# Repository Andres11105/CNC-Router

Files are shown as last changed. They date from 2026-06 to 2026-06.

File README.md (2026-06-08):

# CNC Router

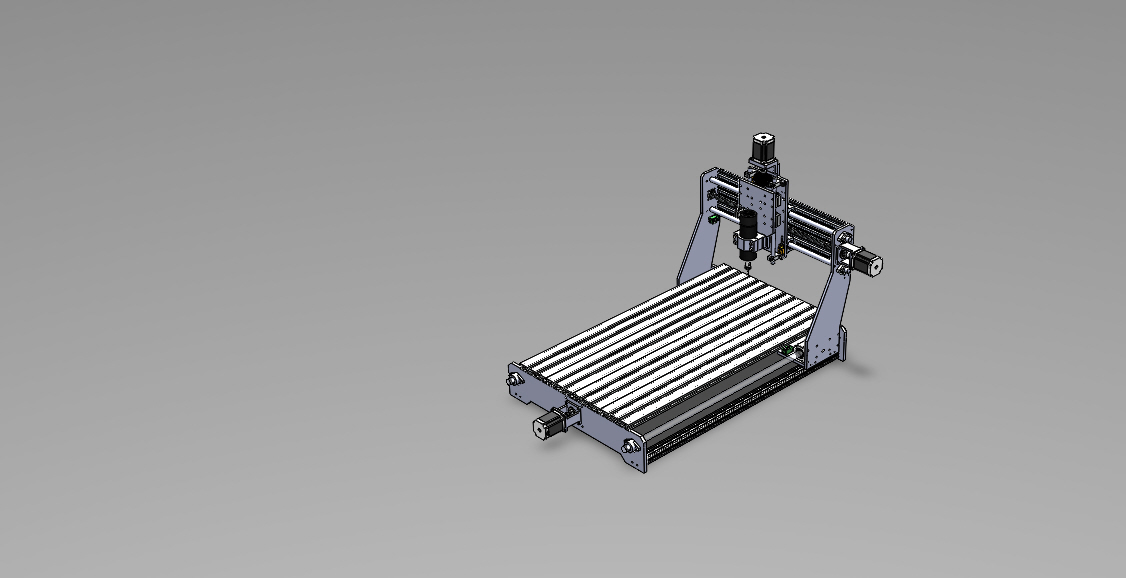
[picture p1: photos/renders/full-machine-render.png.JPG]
full-machine-render


CNC Router

Custom DIY CNC router based on ESP32 + FluidNC, designed for PCB prototyping, wood machining, acrylic fabrication and soft metal machining.

---

## Project Overview

This project documents the design and construction of a custom CNC router developed as an engineering and learning platform focused on:

- CNC machine development
- Embedded systems integration
- Mechanical design
- Electronics and motion control
- FluidNC firmware configuration
- CAD/CAM workflow
- Real-world troubleshooting and calibration

The machine is being developed with a strong focus on modularity, experimentation and practical engineering solutions.

---

## Project Goals

- Build a functional low-cost CNC platform
- Learn CNC machine engineering
- Experiment with ESP32 + FluidNC
- Prototype PCBs and small mechanical parts
- Improve electronics and firmware integration skills
- Document the complete development process

---

## Specifications

| Parameter | Value |
|---|---|
| Work Area | 220 x 430 x 120 mm |
| Controller | ESP32 6x_CNC_Controller + FluidNC + WebUI |
| Firmware | FluidNC |
| Motion System | Lead Screw |
| Machine Type | DIY CNC Router |
| Homing System | Enabled |
| Emergency Stop | Enabled |
| Probe Input | Enabled |

---

## Current Status

- [x] Mechanical structure
- [x] X/Y/Z movement
- [x] FluidNC configuration
- [x] Homing system
- [x] Emergency stop
- [x] Probe input
- [ ] Tool setter
- [x] Cable management
- [ ] Dust collection system
- [ ] Final enclosure

---

## Mechanical Design

The machine structure combines custom-designed components with commercially available mechanical parts.

Some reference CAD models such as motors, lead screws and standard mechanical components were obtained from public engineering libraries like GrabCAD to accelerate assembly and integration workflows.

---

## Electronics

Main electronics currently used in the project:

* ESP32-based "6x_CNC_Controller"
* FluidNC firmware
* Bart Dring WebUI interface
* Stepper motor drivers
* External power supply system
* Emergency stop (E-Stop) circuit
* Probe input system
* Homing/limit switches
* Motion control wiring
* Shielded signal and motor wiring
* Cooling system for drivers and electronics
* Spindle control interface
* USB and WiFi connectivity
* GPIO-based machine control inputs
* Custom machine wiring and cable routing

The electronics architecture focuses on modularity, reliability and ease of maintenance while keeping the system flexible for future upgrades and experimentation.

---

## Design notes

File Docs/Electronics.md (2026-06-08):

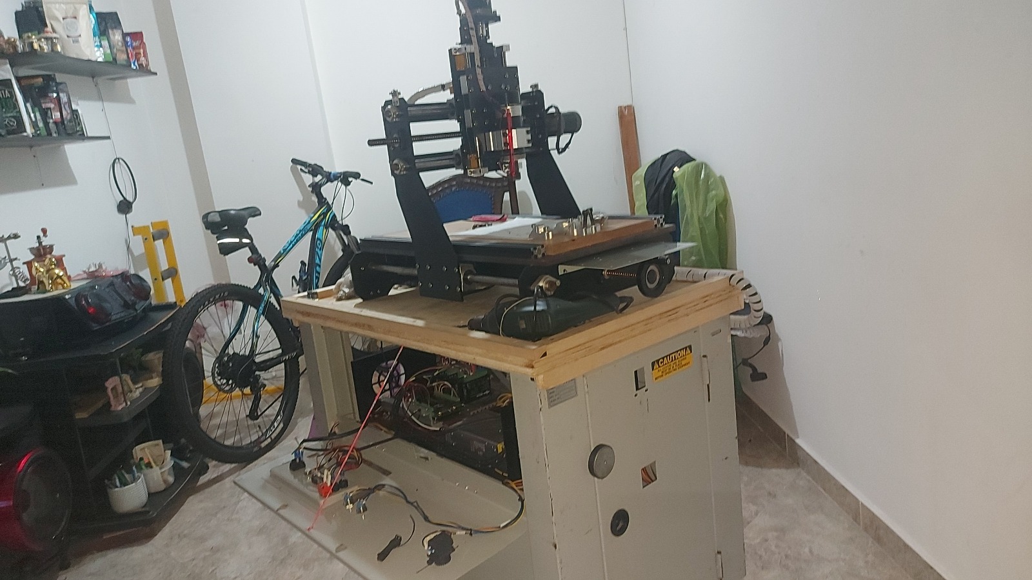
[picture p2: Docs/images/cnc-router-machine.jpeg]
CNC Router


# Electronics Overview

The CNC router uses an ESP32-based control system running FluidNC firmware combined with external motion control electronics and distributed power systems.

The electrical system was designed with a focus on:

* Modularity
* Accessibility
* Low-cost implementation
* Ease of maintenance
* Future scalability

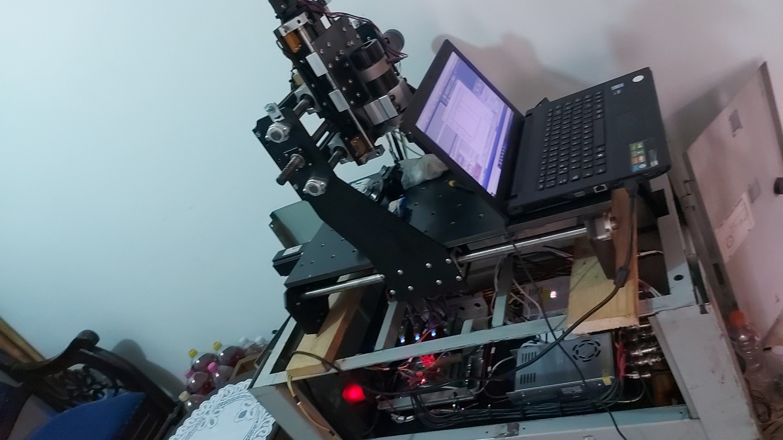
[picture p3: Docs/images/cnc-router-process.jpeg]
Router Assembly Process


---

## Main Electronics

Current electronics used in the machine:

| Component | Description |
| --- | --- |
| CNC Interface | ESP32 6x_CNC_Controller |
| Firmware | FluidNC |
| Motion Drivers | TB6600 stepper drivers |
| Stepper Motors | Nema23 stepper motors (~3Nm) |
| Spindle System | 500W 48V Brushless Spindle Kit |
| Spindle Driver | BLDC spindle driver |
| Main Motion Supply | 24V power supply |
| Spindle Supply | 48V power supply |
| Logic Supply | 12V power supply |
| Limit Switches | Inductive sensors |

The Y-axis motors are newer units while the X and Z axis motors were reused from previous CNC-related projects and experimentation platforms.

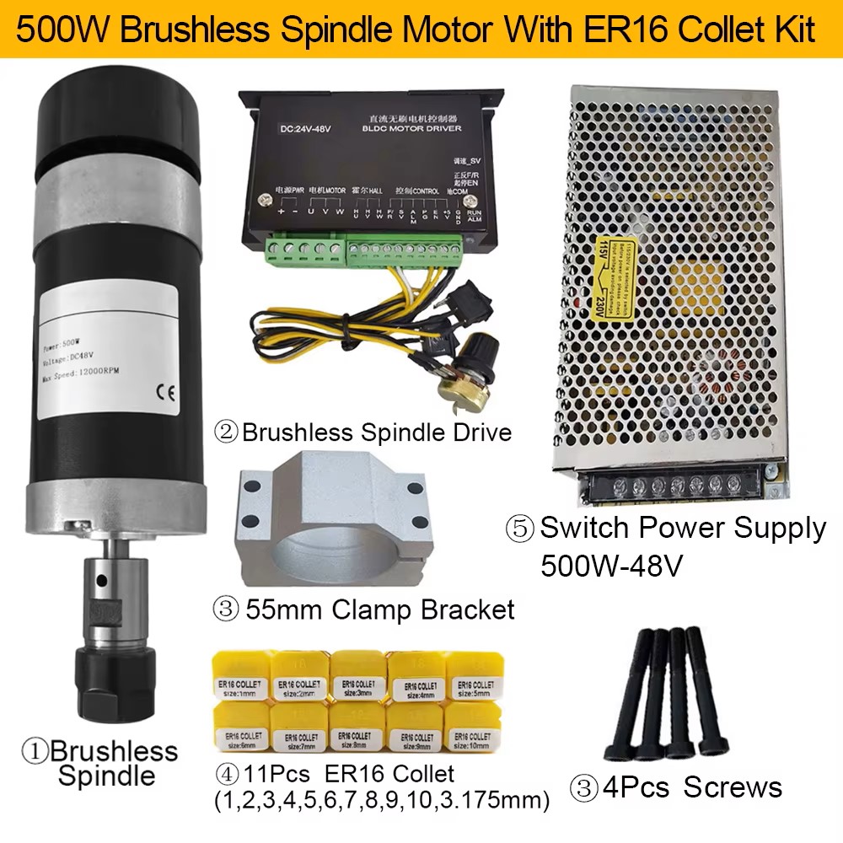
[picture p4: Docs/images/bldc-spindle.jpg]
BLDC Spindle

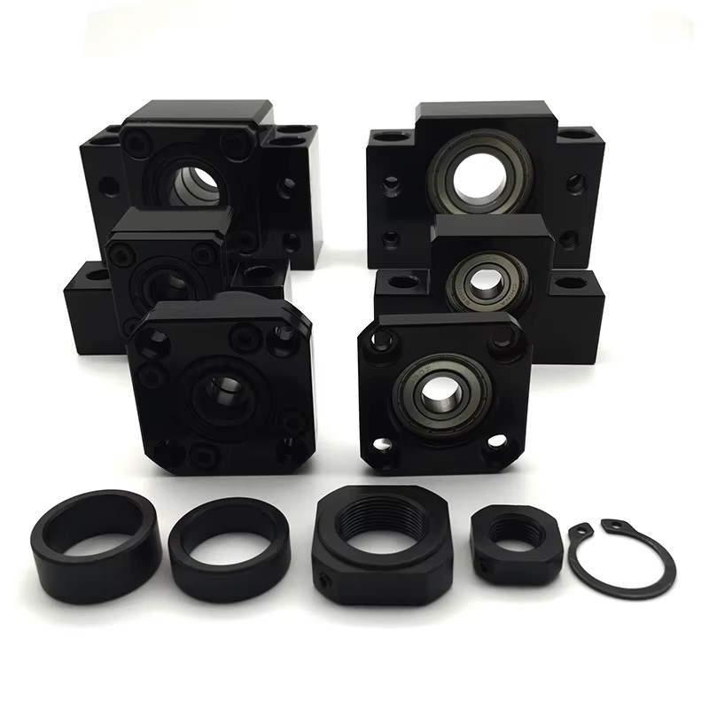
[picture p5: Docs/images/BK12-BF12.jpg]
BK12 and BF12 Supports

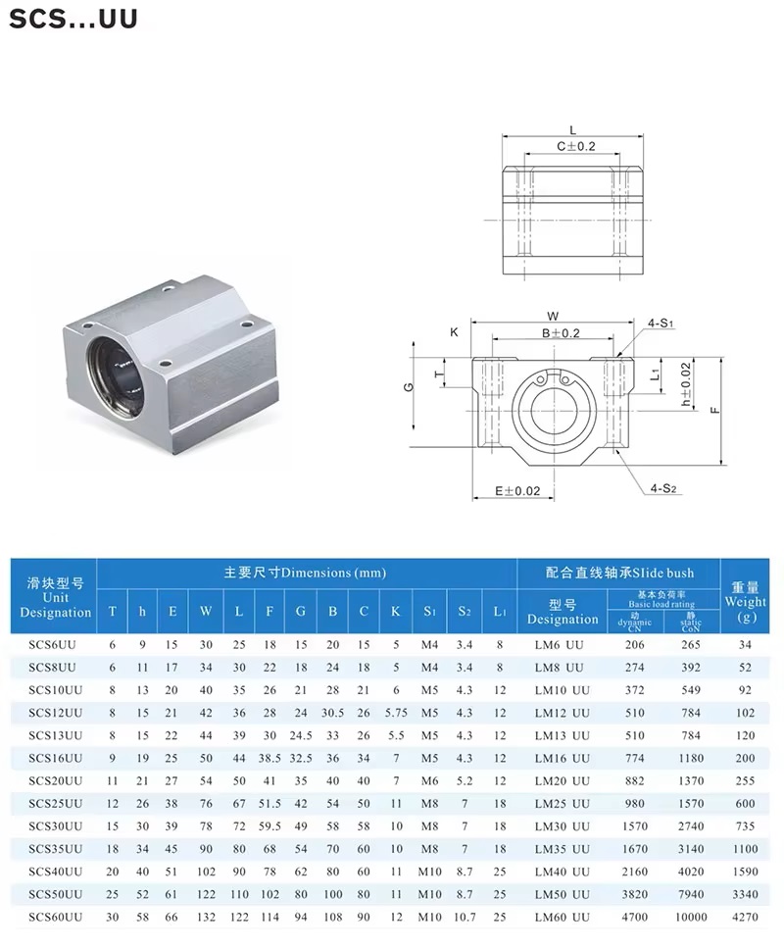
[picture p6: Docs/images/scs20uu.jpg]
SCS20UU Bearings

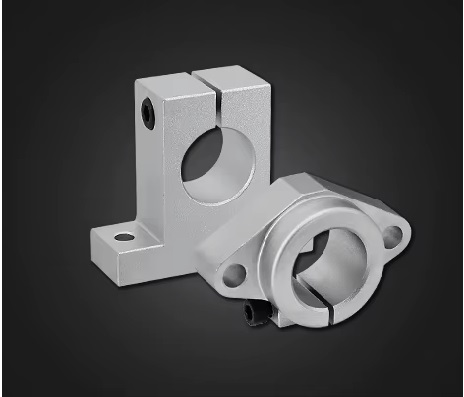
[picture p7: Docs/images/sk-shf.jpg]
SK and SHF Supports

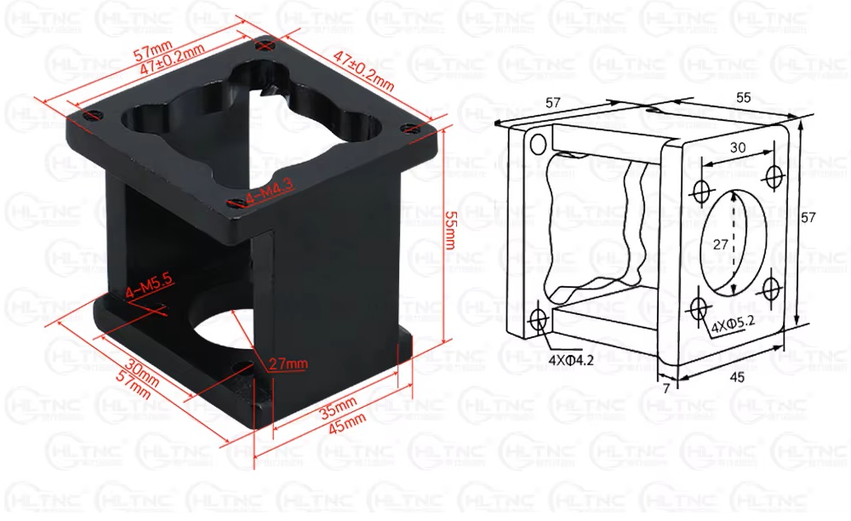
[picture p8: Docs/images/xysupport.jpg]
XY Axis Support
 
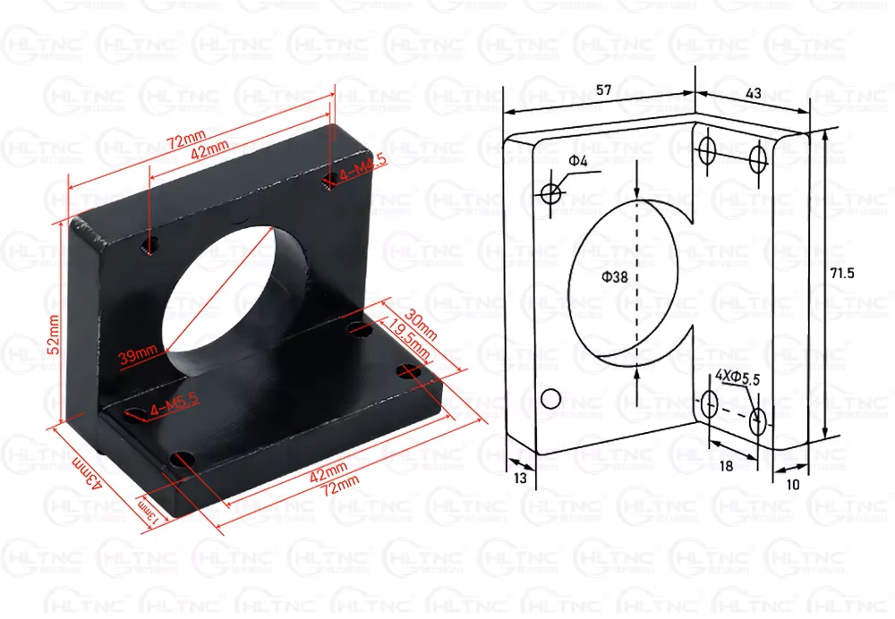
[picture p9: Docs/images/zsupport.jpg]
Z Axis Support


---

## CNC Interface

The machine currently uses an ESP32-based 6x_CNC_Controller running FluidNC firmware.

The controller ecosystem follows the hardware and firmware approach proposed by Bart Dring for FluidNC systems.

The interface includes:

* Start button
* Stop button
* Emergency stop input
* Probe input
* Homing system
* Manual controls
* External driver integration

A small cooling turbine is currently installed for airflow around the ESP32 interface and controller electronics.

---

## Spindle Configuration

The spindle system currently uses:

> DC Brushless Spindle Motor Kit 500W 48V Air Cooled

The spindle wiring was designed to support both:

* Manual spindle operation
* FluidNC-controlled operation

allowing flexible machine usage during testing, maintenance and firmware experimentation.

---

## Motion Control System

The motion system uses external TB6600 stepper drivers combined with Nema23 stepper motors.

Current machine motion architecture:

| Axis | Motor Type | Linear Shaft |
| --- | --- | --- |
| X Axis | Nema23 | 16 mm |
| Y Axis | Nema23 | 20 mm |
| Z Axis | Nema23 | 12 mm |

Inductive limit switches are currently used for homing and machine protection.

---

## Homing and Recovery System

During machine operation, certain failure conditions may leave the limit switches continuously activated, preventing normal machine movement.

To simplify machine recovery during these situations, an additional manual override push-button was implemented.

This button temporarily interrupts the limit switch signal, allowing the machine to be manually moved back into a safe position before executing the homing process again.

This solution was implemented as a practical recovery mechanism during testing and troubleshooting procedures common in DIY CNC developments.

---

## Wiring Philosophy

The electrical system was wired with a modular and serviceable approach in mind.

Special attention was given to separating:

* Power distribution
* Signal wiring
* Motion control wiring
* Safety systems

The electronics enclosure remains easily accessible for:

* Maintenance
* Troubleshooting
* Firmware updates
* Driver replacement
* Future upgrades

Further improvements such as advanced cable management, EMI reduction and enclosure refinements may be implemented in future revisions of the project.

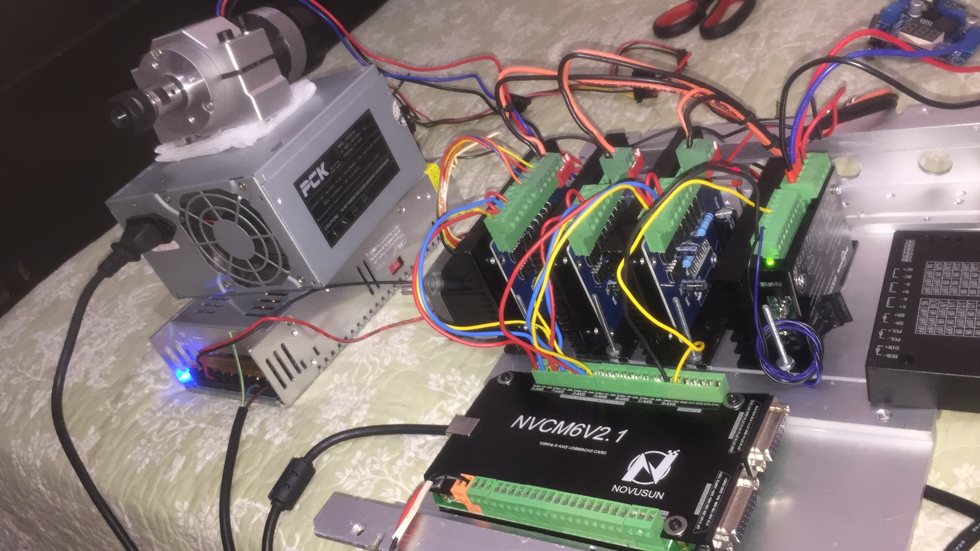
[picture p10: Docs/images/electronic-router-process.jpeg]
Electronics Assembly Process

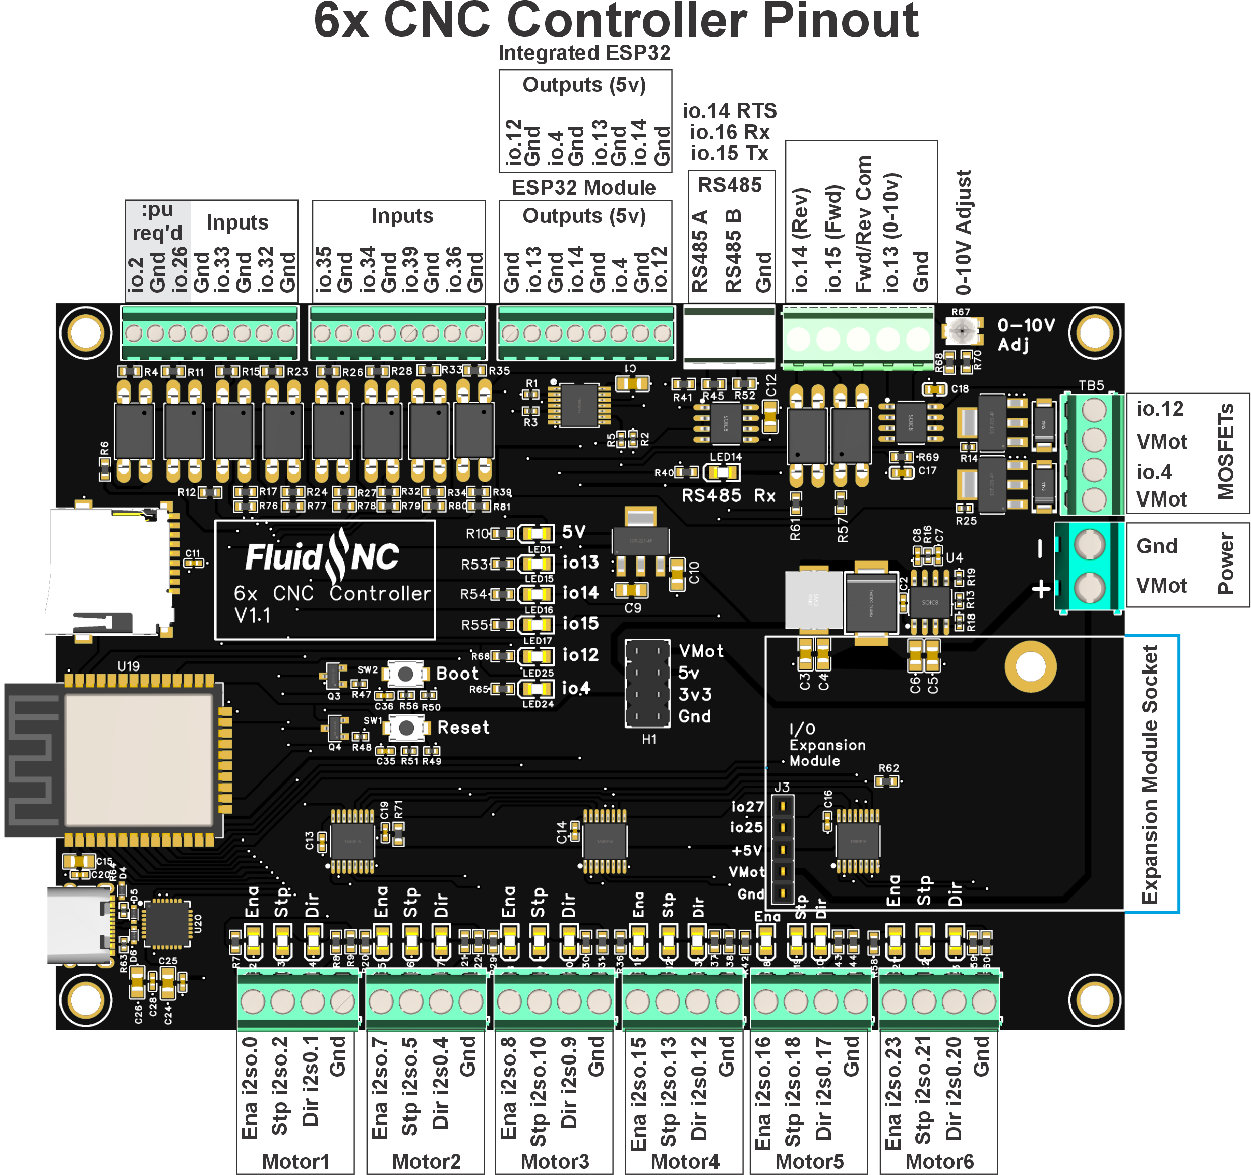
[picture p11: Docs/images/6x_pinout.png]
6x CNC Controller Pinout

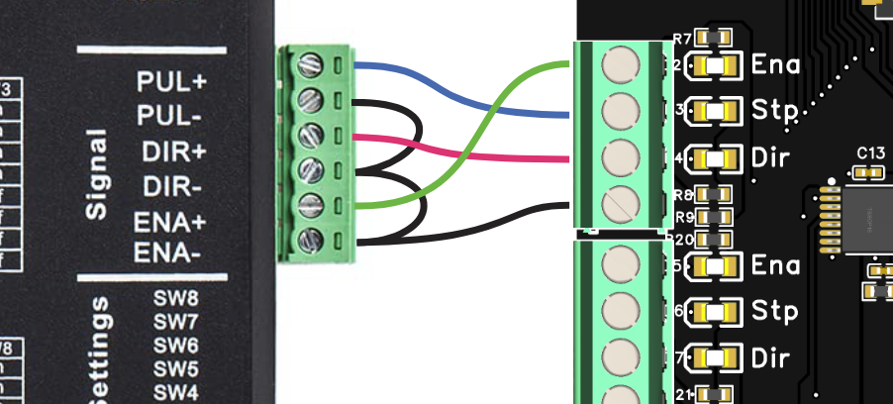
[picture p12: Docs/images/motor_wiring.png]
Motor Wiring

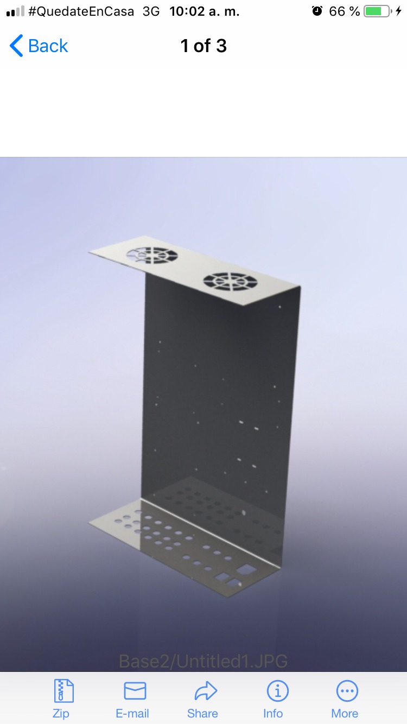
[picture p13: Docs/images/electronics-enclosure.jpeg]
Electronics Enclosure


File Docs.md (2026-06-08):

# Mechanical Design Philosophy

Mechanical Design

This section documents the engineering decisions, manufacturing processes, mechanical challenges and design philosophy behind the CNC router development.

The machine was developed as a long-term DIY engineering and learning project focused on CNC systems, electronics integration, firmware configuration and mechanical design.

---

## Industrial Inspiration

During an internship process at EAFIT University in Medellín, Colombia, conversations with the CNC laboratory machine operator provided valuable practical insight into industrial CNC machine design principles.

Special emphasis was placed on the importance of:

* Recirculating ball screws
* Mechanical tolerances
* Structural rigidity
* Backlash reduction

After researching the topic further, the importance of motion precision and tolerance management became evident, especially within the limitations commonly present in DIY CNC developments.

For this reason, 1605 recirculating ball screws were implemented on all machine axes to reduce backlash and improve positional accuracy.

---

## Project Philosophy

This CNC router was developed primarily as:

* A learning platform
* A long-term hobby project
* An engineering experimentation platform
* A low-cost CNC development environment

Because the project was built using limited personal resources, considerable effort was dedicated to optimizing:

* Material selection
* Manufacturing methods
* Component acquisition
* Mechanical design
* Scalability possibilities

---

## Prototyping Strategy

Multiple laser-cut MDF prototypes were manufactured during early development stages due to their:

* Low manufacturing cost
* Fast fabrication time
* Easy modification process
* Material accessibility

This prototyping stage allowed validation of:

* Structural dimensions
* Axis positioning
* Mechanical clearances
* Motion integration
* Assembly procedures

before proceeding to the fabrication of the final RH steel structural components.

The MDF prototyping stage proved extremely valuable for identifying mechanical issues early while reducing material waste and manufacturing costs.

---

## Structural Material Selection

RH steel was selected as the primary structural material mainly due to:

* Budget limitations
* Local material availability
* Manufacturing accessibility

Although RH steel adds considerable weight compared to aluminum CNC structures, the additional mass contributes positively to:

* Vibration damping
* Structural rigidity
* Machine stability

However, the increased structural weight also introduces:

* Higher moving mass
* Increased mechanical stress
* Greater flexion forces
* More demanding alignment procedures

For this project, the added rigidity and lower manufacturing cost were considered acceptable trade-offs.

---

## Workspace Optimization

The machine dimensions were intentionally designed to fit within the footprint of a standard desk workspace.

This decision provided several advantages:

| Advantage | Benefit |
| --- | --- |
| Compact Size | Easier workspace integration |
| Reduced Material Usage | Lower manufacturing costs |
| Improved Accessibility | Easier assembly and maintenance |
| Desktop Footprint | Better adaptation for hobby/lab environments |

while still maintaining enough working area for:

* PCB prototyping
* Wood machining
* Acrylic machining
* Soft metal experimentation

---

## Modular Design

The machine was designed using independent mechanical modules to simplify:

* Manufacturing
* Assembly
* Maintenance
* Future upgrades

### Current Machine Architecture

| Module | Description |
| --- | --- |
| Bed Module | Base structure and transmission |
| Gantry Module | Main bridge structure |
| X-Axis Module | Horizontal displacement system  |
| Z-Axis Module | Vertical motion system |

This modular approach allows individual sections of the machine to be modified or redesigned without rebuilding the complete structure.

---

## Manufacturing Process

Laser cutting was used extensively during both:

* MDF prototyping
* RH steel fabrication

The structural steel plates were laser-cut according to CAD designs; however, some hole tolerances were affected because laser cutting clearances were not fully considered during the design phase.

### Manufacturing Corrections

* Some holes became oversized
* Larger fasteners became necessary
* Additional alignment corrections were required
* Some assemblies required manual adjustment during installation

Several structural alignment corrections also became necessary during assembly due to distortions introduced by welding processes.

> Machine squaring and alignment remain one of the primary areas for future improvement.

---

## Mechanical Challenges

Like many DIY CNC developments, the project presents several common engineering challenges, including:

* Structural flexion caused by machine weight and machining forces
* Mechanical alignment complexity
* Welding-induced dimensional deviations
* Motion system tolerances
* Gantry squaring adjustments

### Current Mechanical Behavior

| Characteristic | Current Result |
| --- | --- |
| Structural Rigidity | Acceptable |
| Vibration Levels | Relatively controlled |
| Backlash Reduction  | Significantly improved |
| Alignment Accuracy  | Requires future improvements |

Despite the machine weight, vibration levels have remained relatively controlled due to the rigidity and damping effect provided by the steel structure.

Backlash reduction has been significantly improved through the use of recirculating ball screws compared to lower-cost transmission alternatives.

---

## Components and Motion System

Several critical mechanical components were acquired through commercial suppliers such as AliExpress to reduce manufacturing complexity and improve reliability.

### Main Purchased Components

* Stepper motor mounts
* Linear shaft supports
* Linear shafts
* BK/BF supports
* Sensors
* Stepper motors
* Spindle system
* Motion accessories

---

## Linear Shaft Configuration

| Axis | Diameter |
| --- | --- |
| Z Axis | 12 mm |
| X Axis | 16 mm |
| Y Axis | 20 mm |

The larger Y-axis shafts were selected due to the higher structural load requirements of the machine.

---

## Motion System

| Component | Specification |
| --- | --- |
| Ball Screws | 1605 Recirculating Ball Screws |
| Support System | BK/BF Supports |
| Linear System | Hardened Steel Shafts |
| Controller Platform | ESP32 + FluidNC |

The CNC controller interface was acquired through ELECROW following the recommendations and hardware ecosystem proposed by Bart Dring for FluidNC systems.

---

## Maintenance and Accessibility

The motion system and linear components remain externally accessible, simplifying:

* Inspection
* Cleaning
* Lubrication
* Preventive maintenance

Although this exposes the system to dust and debris contamination, it considerably improves:

* Maintenance accessibility
* Serviceability
* Mechanical inspection
* Upgrade possibilities

---

## Scalability and Future Upgrades

One of the primary advantages of DIY CNC platforms is their scalability and adaptability.

Virtually any subsystem may be upgraded or redesigned, including:

* Spindle systems
* Motor configurations
* Drivers
* Bearings
* Linear systems
* Controllers
* Firmware interfaces

### Potential Upgrade Consequences

| Upgrade | Possible Required Changes |
| --- | --- |
| Larger Spindle | Stronger Z-axis support |
| Bigger Motors | Driver replacement |
| Higher Speed Motion | Structural reinforcement  |
| Heavier Components  | Motion recalibration |

These modifications typically introduce secondary engineering consequences requiring:

* Additional redesign
* Structural reinforcement
* Motion recalibration
* Firmware adjustments

---

## Development Philosophy

The objective of this project is not only to build a functional CNC machine, but also to document the complete engineering process behind a real-world DIY CNC development platform.

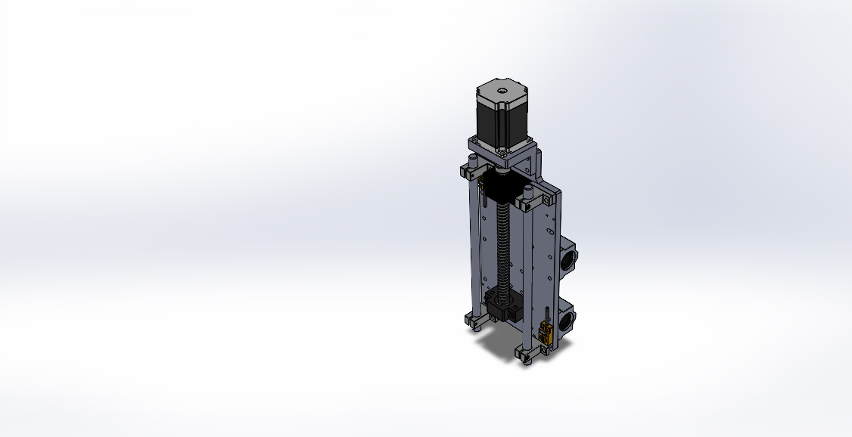
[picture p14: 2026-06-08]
photos/renders/DeslizableEjeX-render.JPG

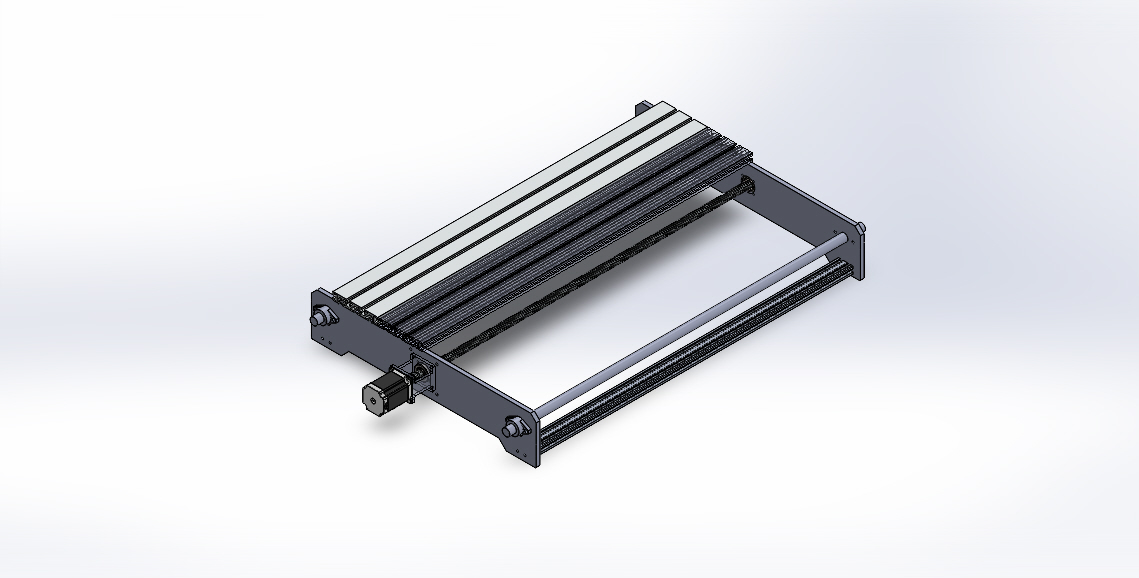
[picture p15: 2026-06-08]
photos/renders/Axis-Y-render.JPG

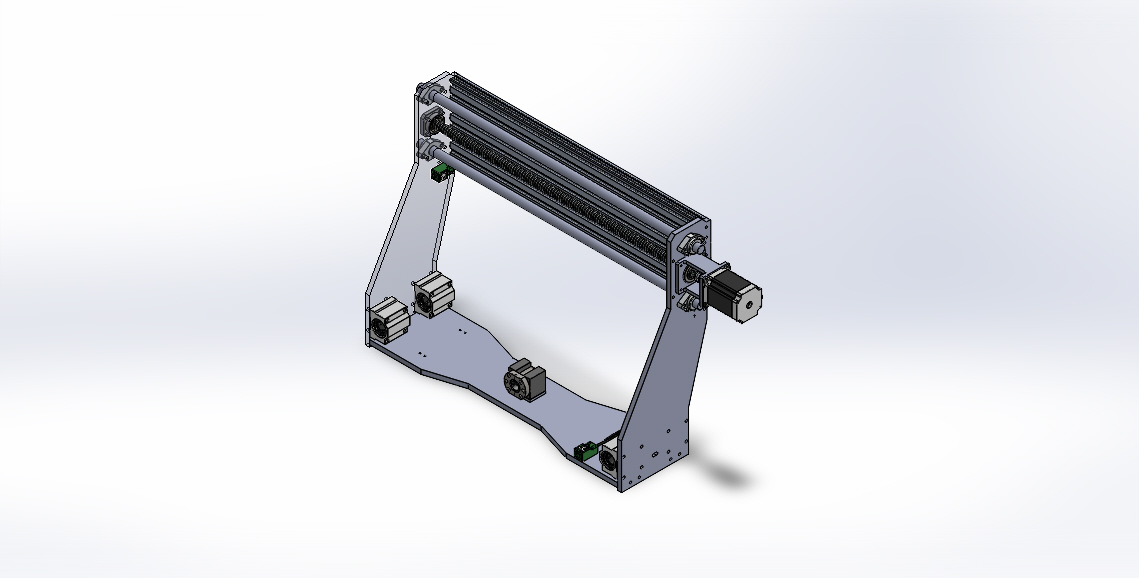
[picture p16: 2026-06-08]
photos/renders/Axis-X-render.JPG

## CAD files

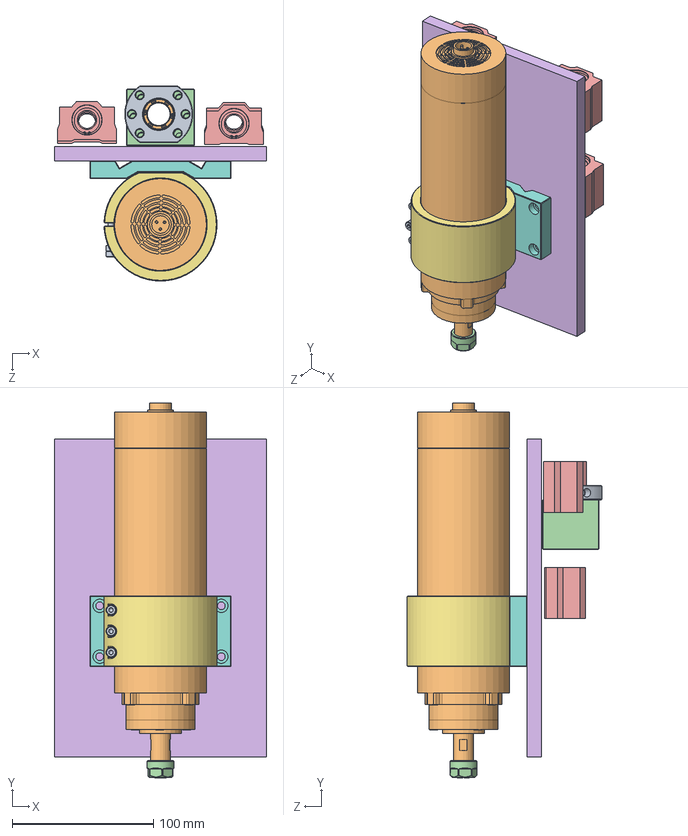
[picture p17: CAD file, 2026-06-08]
Cad/EnsamblajeZ.SLDASM
150.0 x 265.2 x 138.0 mm
SFU1605-1610-1
SFU1605-1610-3
SFU1605-1610-2
HD16
SC12UU x 4
Pieza3
CNCM.01.06.201
CNCM.01.06.202
socket head cap screw_am x 7
Шпиндель 1,5 кВт
ER11
ER11-T1

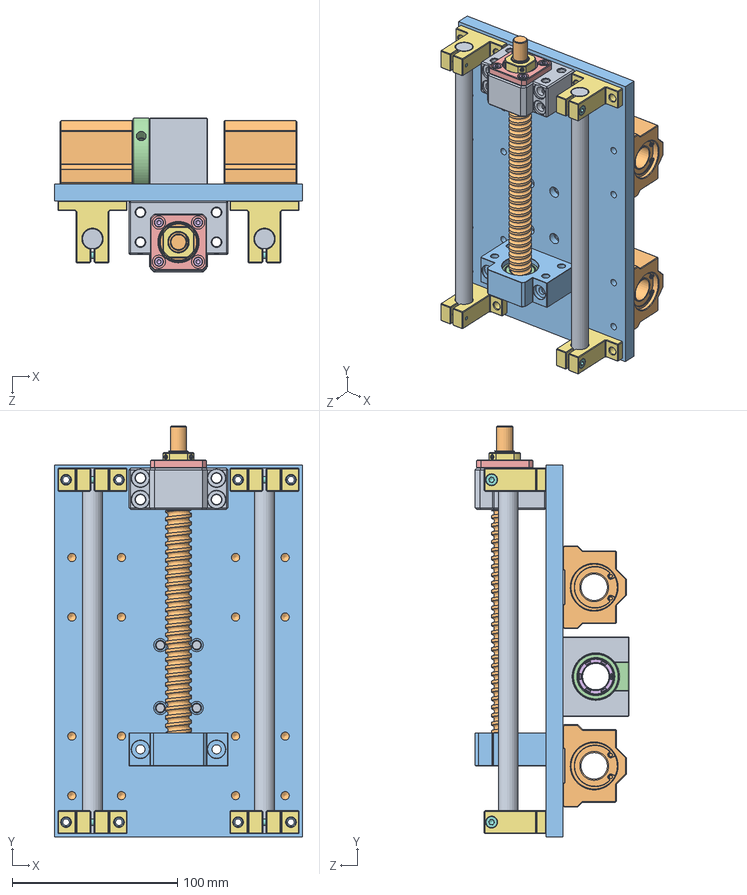
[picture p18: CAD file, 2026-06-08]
Cad/DeslizableEjeX.SLDASM
150.0 x 248.5 x 93.0 mm
HD16
sc16uu_bearing x 4
Pieza1
SFU1605-1610-1
SFU1605-1610-3
SFU1605-1610-2
Shaft support SK12 x 4
m4x16 x 4
BK12-1
BK12-2 x 2
BK12-3 x 2
6001-Bearing x 2
BK12-4
socket head cap screw_din x 4
BK12-5
socket set screw cup point_din x 2
Shaft200mm x 2
RM1605-C7 L200
BF12
6000Z

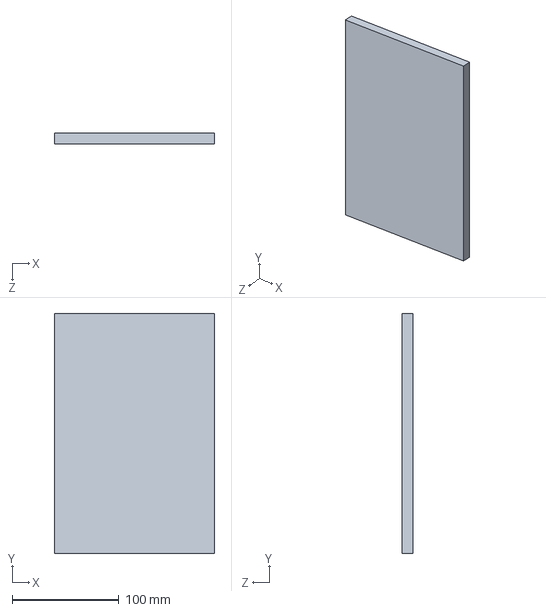
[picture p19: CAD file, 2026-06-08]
Cad/Pieza3.SLDPRT
150.0 x 225.0 x 10.0 mm

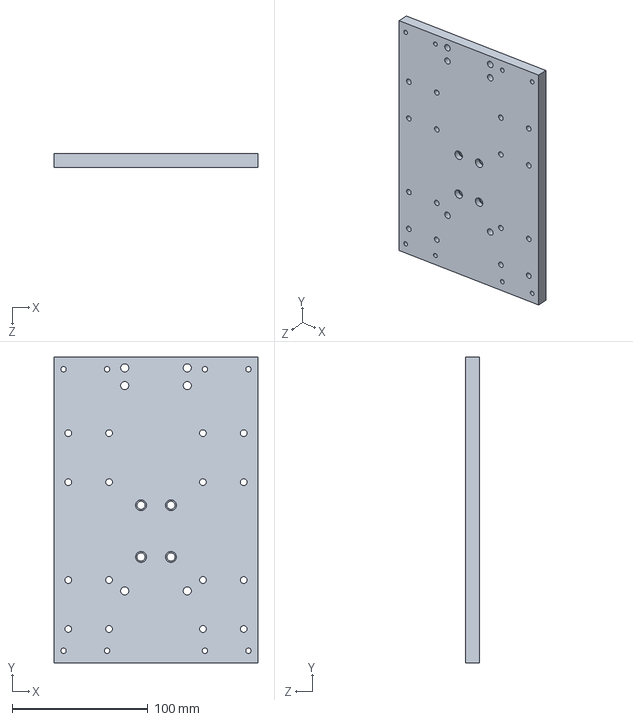
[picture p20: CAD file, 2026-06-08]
Cad/Pieza1.SLDPRT
150.0 x 225.0 x 10.0 mm

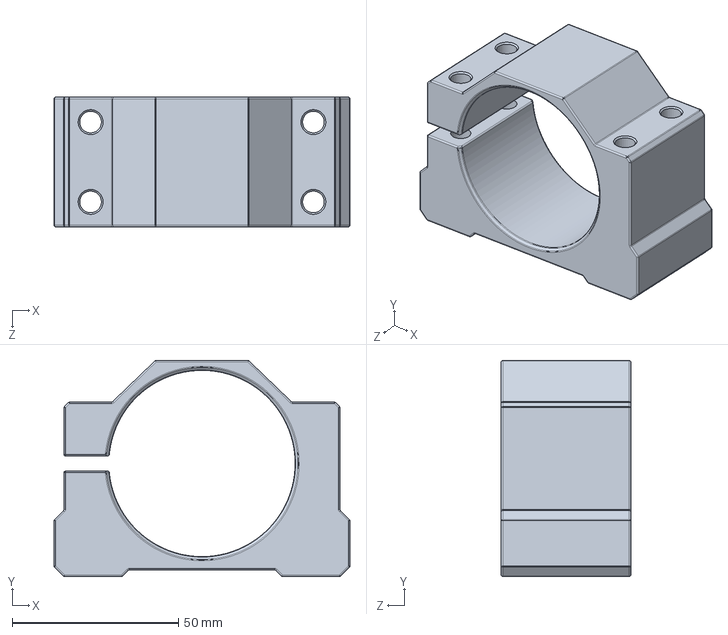
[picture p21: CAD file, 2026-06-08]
Cad/56.SLDPRT
89.0 x 65.0 x 39.0 mm

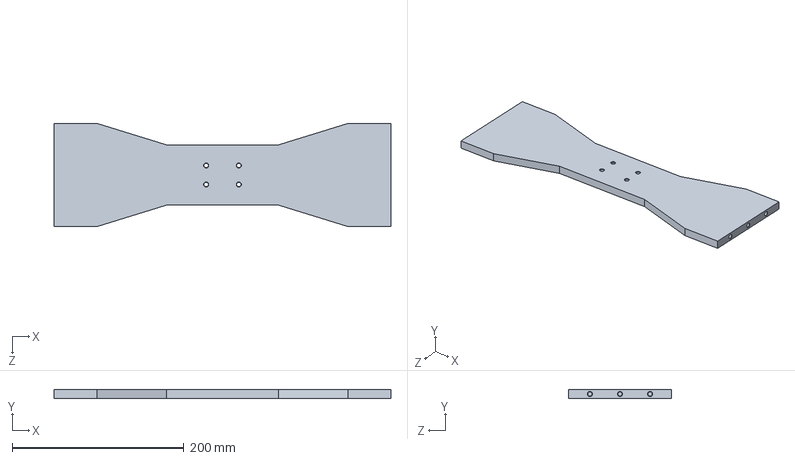
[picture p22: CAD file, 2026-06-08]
Cad/Pieza2.SLDPRT
392.0 x 10.0 x 120.0 mm

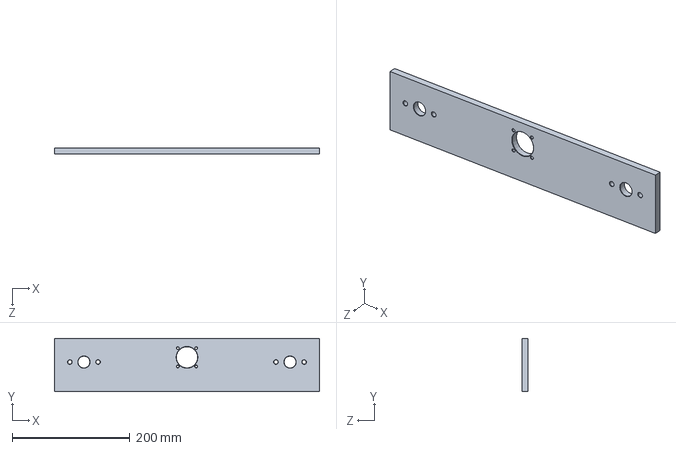
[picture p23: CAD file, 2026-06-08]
Cad/PiezaFrontalBaseY.SLDPRT
450.0 x 90.0 x 10.0 mm

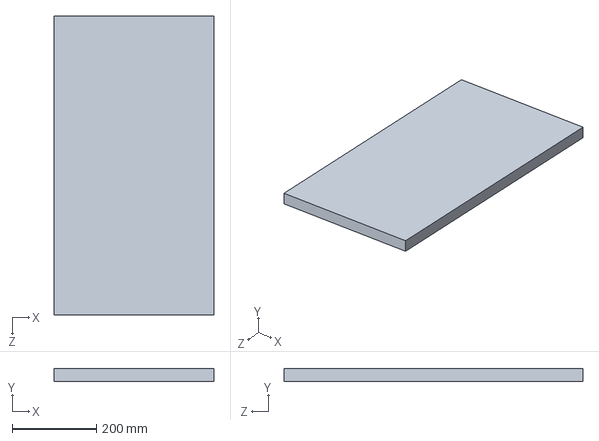
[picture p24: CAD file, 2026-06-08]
Cad/Pieza4.SLDPRT
380.0 x 30.0 x 710.0 mm

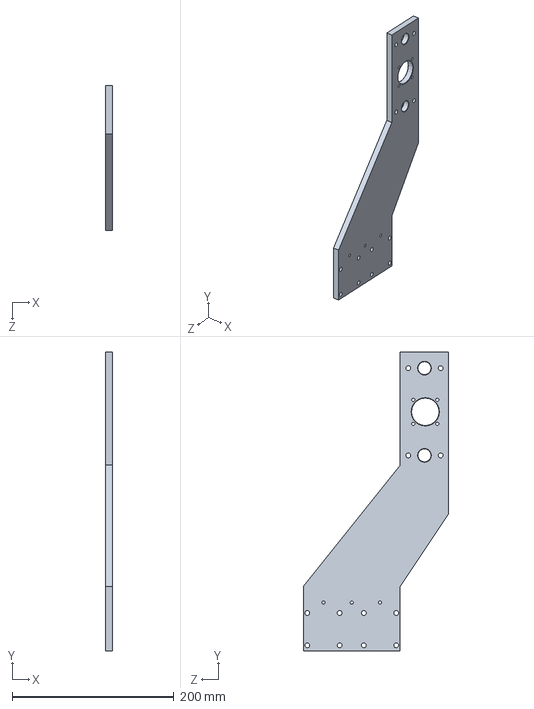
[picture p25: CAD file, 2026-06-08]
Cad/verticalYizqq.SLDPRT
9.00 x 370.0 x 180.0 mm

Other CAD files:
Cad/PiezaTraseraBaseY.SLDPRT
Cad/verticalYder.SLDPRT

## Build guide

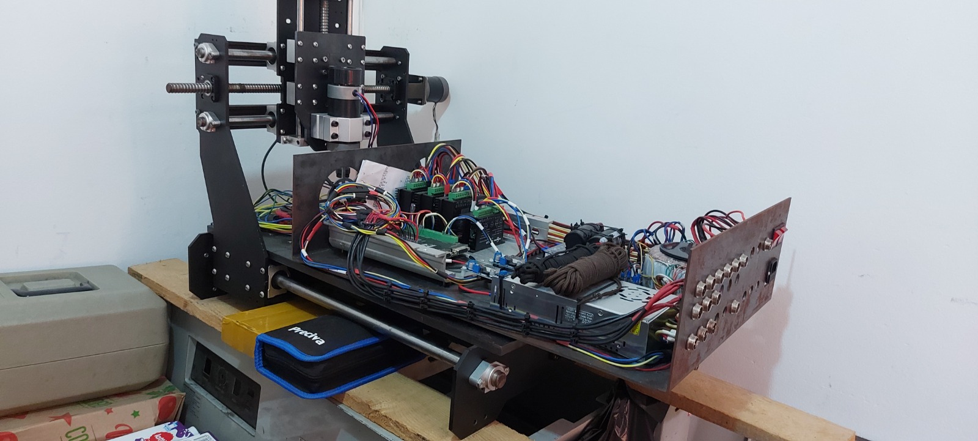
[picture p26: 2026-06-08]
Docs/images/wiring-process.jpeg

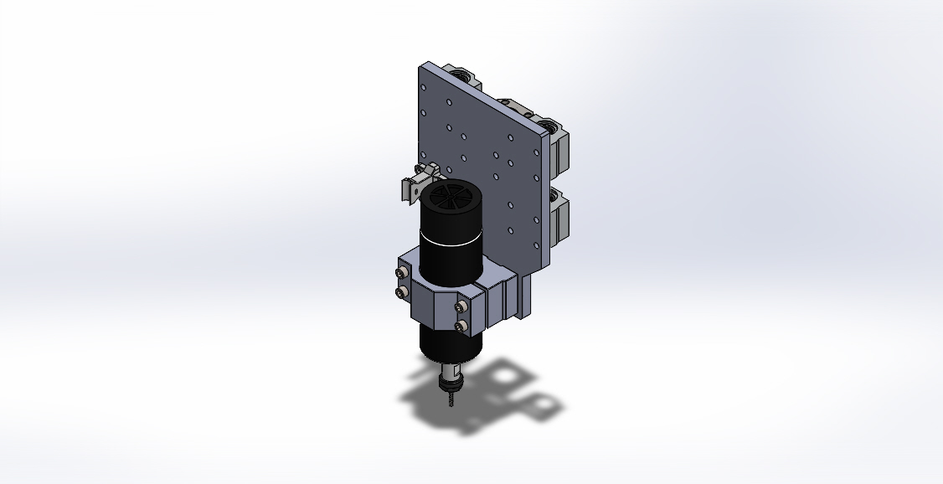
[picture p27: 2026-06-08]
photos/renders/EnsamblajeZ-render.JPG

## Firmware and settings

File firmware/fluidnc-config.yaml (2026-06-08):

board: 6x CNC Controller
name: xyz 10v Pendant
meta: (13-03-2025) by Andres11105

stepping:
  engine: I2S_STREAM
  idle_ms: 60000
  pulse_us: 4
  dir_delay_us: 1
  disable_delay_us: 0

axes:
  shared_stepper_disable_pin: NO_PIN
  x:
    steps_per_mm: 320.000
    max_rate_mm_per_min: 1500.000
    acceleration_mm_per_sec2: 100.000
    max_travel_mm: 220.000
    soft_limits: true
    homing:
      cycle: 2
      positive_direction: false
      mpos_mm: 4.000
      feed_mm_per_min: 500.000
      seek_mm_per_min: 800.000
      settle_ms: 500
      seek_scaler: 1.100
      feed_scaler: 1.100

    motor0:
      limit_neg_pin: NO_PIN
      limit_pos_pin: NO_PIN
      limit_all_pin: gpio.2:low:pu
      hard_limits: true
      pulloff_mm: 5.000
      standard_stepper:
        step_pin: I2SO.2
        direction_pin: I2SO.1:low
        disable_pin: I2SO.0

  y:
    steps_per_mm: 320.000
    max_rate_mm_per_min: 1500.000
    acceleration_mm_per_sec2: 100.000
    max_travel_mm: 420.000
    soft_limits: true
    homing:
      cycle: 2
      positive_direction: false
      mpos_mm: 4.000
      feed_mm_per_min: 500.000
      seek_mm_per_min: 800.000
      settle_ms: 500
      seek_scaler: 1.100
      feed_scaler: 1.100

    motor0:
      limit_neg_pin: NO_PIN
      limit_pos_pin: NO_PIN
      limit_all_pin: gpio.26:low:pu
      hard_limits: true
      pulloff_mm: 5.000
      standard_stepper:
        step_pin: I2SO.5
        direction_pin: I2SO.4:high
        disable_pin: I2SO.7

  z:
    steps_per_mm: 320.000
    max_rate_mm_per_min: 1000.000
    acceleration_mm_per_sec2: 100.000
    max_travel_mm: 120.000
    soft_limits: false
    homing:
      cycle: 1
      positive_direction: true
      mpos_mm: 100.000
      feed_mm_per_min: 500.000
      seek_mm_per_min: 800.000
      settle_ms: 500
      seek_scaler: 1.100
      feed_scaler: 1.100

    motor0:
      limit_neg_pin: NO_PIN    
      limit_pos_pin: NO_PIN
      limit_all_pin: gpio.33:low:pu
      hard_limits: true
      pulloff_mm: 5.000
      standard_stepper:
        step_pin: I2SO.10
        direction_pin: I2SO.9:low
        disable_pin: I2SO.8
        
uart1:
  txd_pin: gpio.25
  rxd_pin: gpio.27
  rts_pin: NO_PIN
  cts_pin: NO_PIN
  baud: 1000000
  mode: 8N1

uart_channel1:
  report_interval_ms: 75
  uart_num: 1

i2so:
  bck_pin: gpio.22
  data_pin: gpio.21
  ws_pin: gpio.17

spi:
  miso_pin: gpio.19
  mosi_pin: gpio.23
  sck_pin: gpio.18

sdcard:
  card_detect_pin: NO_PIN
  cs_pin: gpio.5
  
probe:
  pin: gpio.34:low
  toolsetter_pin: NO_PIN
  check_mode_start: false
  
# Using MOSFETs (Check Spindle Pin Usage
coolant:
  flood_pin: gpio.12
  mist_pin: gpio.4
  delay_ms: 0

start:
  must_home: false
  
control:
#  safety_door_pin: NO_PIN
#  reset_pin: NO_PIN
  feed_hold_pin:    gpio.39
  cycle_start_pin:  gpio.36
#  macro0_pin: NO_PIN
#  macro1_pin: NO_PIN
#  macro2_pin: NO_PIN
#  macro3_pin: NO_PIN
#  fault_pin: NO_PIN
  estop_pin:        gpio.35

10V:
   forward_pin: gpio.15
   reverse_pin: gpio.14
   pwm_hz: 5000
   output_pin: gpio.13
   enable_pin: NO_PIN
   direction_pin: NO_PIN
   disable_with_s0: false
   s0_with_disable: true
   spinup_ms: 0
   spindown_ms: 0  
   tool_num: 0
   speed_map: 0=0.000% 500=0.000% 12000=100.000%
   off_on_alarm: false

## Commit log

2026-06-08 Create Cad
2026-06-08 Create Assemblies
